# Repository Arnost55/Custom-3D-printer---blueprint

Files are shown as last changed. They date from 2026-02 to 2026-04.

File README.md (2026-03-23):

<div align="center">

  <h2>By Arnošt Dobrucký</h2>

  <p display="inline">
  
  <a href="https://creativecommons.org/licenses/by-nc/4.0/">
    </a> <a href="https://hackclub.com/">
    
  </a>

  </p>

  <h4>A homemade 3D printer that just works.     :)</h4>
</div>

<sub>This work is licensed under a
[Creative Commons Attribution-NonCommercial 4.0 International License](https://creativecommons.org/licenses/by-nc/4.0/).
</sub>

# Table of contents
- [About](#about)
- [BOM (Bill of Materials)](#bom-bill-of-materials)
- [How to Build the Blueprint 3D Printer](#how-to-build-the-blueprint-3d-printer)
  - [Section 1 — Materials and Tools](#section-1--materials-and-tools)
  - [Section 2 — Frame and Base Construction](#section-2--frame-and-base-construction)
  - [Section 3 — Machining the Parts](#section-3--machining-the-parts)
  - [Section 4 — Assembly](#section-4--assembly)
  - [Section 5 — Mounting the BTT Eddy Duo and Display](#section-5--mounting-the-btt-eddy-duo-and-display)
  - [Section 6 — Klipper Installation](#section-6--klipper-installation)
  - [Section 7 — Calibration](#section-7--calibration)
- [Images / Videos](#imagesvideos)
- [Future Plans](#future-plans)
- [Warranty](#warranty)
- [TO DO](#to-do)

---

# About

The Blueprint 3D printer is a fully custom-built FDM 3D printer designed and constructed from scratch by Arnošt and his grandfather. Every structural component was hand-machined from steel with no pre-made frame or kit involved. The project took a total of 420 hours across design, fabrication, assembly, and calibration.

---

### Specifications

| Spec | Value |
| --- | --- |
| Build Volume | 175mm × 210mm × 200mm |
| Frame Material | Standard steel |
| Motion System | **Cartesian** |
| Mainboard | BTT Manta E3EZ v1.0 |
| Hotend | BIQU H2 V2S Lite |
| Nozzle Diameter | 0.4mm |
| Heated Bed | Yes 235mm × 235mm |
| Extruder Type | Direct Drive |
| Bed Leveling Probe | BTT Eddy Duo |
| Stepper Motors | 3× BIQU NEMA 17 |
| Power Supply | 24V — 300W |
| Control Board Host | BTT CB1 |
| Display | BTT TFT35 |
| Firmware | Klipper |
| Web Interface | Mainsail |
| Print Surface | Tape (e.g. Duct tape) |
| Max Hotend Temp | 250°C |
| Max Bed Temp | 80°C  |

---

### Key Features

- Fully custom steel frame — no off-the-shelf structural parts
- Klipper firmware with Mainsail web interface for remote control and monitoring
- BTT Eddy probe for automatic bed mesh compensation
- Custom-machined motor mounts, bed holder, and extruder mount
- Internal cable management with pre-drilled routing holes
- PSU and mainboard housed inside the base for a clean build
- Painted black steel finish throughout

# BOM (bill of materials)

| Item Description | SKU | Qty | Unit Price (USD) | Total (USD) |
| --- | --- | --- | --- | --- |
| [GT2 Timing Pulley 16/20 Teeth (20 teeth-Width 6mm-bore 8mm/10pcs)](https://biqu.equipment/products/10pcs-gt2-timing-pulley-20-teeth-alumium-bore-5mm-fit-for-gt2-belt-width-6mm-with-lower-price-for-3d-printer-part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) | WCL000020*10 | 1 | $7.21 | 7.21 |
| [BIQU H2 V2S Lite Extruder Complete Kit](https://biqu.equipment/products/h2-v2s-lite?variant=40121207554146) | 1060000581 | 1 | $58.06 | 58.06 |
| [GT2-6mm Open Timing Belt (Rubber Black/6MM/10m)](https://biqu.equipment/products/hot-sale-10meter-gt2-6mm-open-timing-belt-width-6mm-gt2-belt-for-3d-printer-parts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) | 3020040150*10 | 1 | $9.48 | 9.48 |
| [BIQU Nema17 c42 motor CNC stepper motor (Length 33mm)](https://biqu.equipment/products/nema17-c42-motor-cnc-stepper-motor-length-33mm-stepping-motor-1-33a-for-3d-printer-for-cnc-xyz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) | 3010080001 | 3 | $11.80 | 35.39 |
| [BIGTREETECH Eddy Duo (Support USB or CAN)](https://biqu.equipment/products/bigtreetech-eddy?variant=41018205438050) | 1060000710 | 1 | $19.64 | 19.64 |
| [Flexible shaft Coupler 58mm (58/Black/4pcs)](https://biqu.equipment/products/3d-printer-stepper-motor-flexible-coupling-coupler-shaft-couplings-5mm-8mm-25mm-flexible-shaft-freeshipping-1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) | 3010050224*4 | 1 | $6.64 | 6.64 |
| [BIGTREETECH TFT35 SPI V2.1 Touch Screen for CB1](https://biqu.equipment/collections/lcd-screen/products/bigtreetech-tft35-spi-v2-1-touchscreen-io2can-module) | 1040000035 | 1 | $14.29 | 14.29 |
| [BIGTREETECH Manta E3EZ V1.0 + 5pcs EZ2209 + CB1 V2.2](https://biqu.equipment/products/bigtreetech-manta-e3ez-v1-0-for-ender3-ender3pro-ender5?variant=40214245081186) | 1020000405+… | 1 | $58.90 | 58.9 |
| [Wires](https://www.aliexpress.com/item/1005006801644262.html?spm=a2g0o.order_list.order_list_main.5.73a21802GiWhg9) | _____ | 4 | _____ | 13.58 |
| [T8 Lead Screw THSL-300-8D Trapezoidal Rod](https://www.aliexpress.com/item/1005003312523975.html?spm=a2g0o.order_list.order_list_main.36.73a21802GiWhg9) | _____ | 2 | $7.04 | 7.04 |
| [Meanwell PSU 350W](https://www.aliexpress.com/item/1005006092154615.html?spm=a2g0o.order_list.order_list_main.42.73a21802GiWhg9) | _____ | 1 | $40.34 | 40.34 |
| [Linear Rails](https://www.aliexpress.com/item/1005009577277063.html?spm=a2g0o.order_list.order_list_main.30.73a21802GiWhg9) | _____ | 3 | $18.81 | 56.43 |
| [Heat bed 235x235](https://www.aliexpress.com/item/1005007288279620.html?spm=a2g0o.order_list.order_list_main.11.73a21802GiWhg9) | _____ | 1 | $22.64 | 22.64 |
| Steel — from my grandpas garage | _____ | _____ | _____ | not yet defined |
| TOTAL: |  |  |  | 354.64 |

# How to Build the Blueprint 3D Printer

This guide explains how to build the custom steel-frame 3D printer from scratch. It covers everything from picking your materials to getting your first print. There is no pre-made kit for this — every part is made by hand. You will need basic metalworking skills, access to a drill and grinder, and patience.

## Section 1 — Materials and Tools

### Overview

Before you start cutting anything you need to have everything ready. This printer is built almost entirely from steel. You will also need a set of standard 3D printer electronics.

### What You Need

**Structural materials**

- Standard steel flat bar and sheet — for the base plate, Z-axis base, bed holder, motor mounts, and extruder mount
- Linear rails (1x for X-axis, 1x for Z-axis)
- Linear rods (1x for Z-axis)
- Lead screw with brass nut (for Z-axis)
- Aluminium extrusion or steel rod for frame uprights
- The display mount (needs to be 3D printed)
- The BTT eddy mount (needs to be 3D printed)

**Electronics**

- Mainboard (BTT Manta E3EZ v1.0)
- BTT CB1 v2.2 (runs Klipper on the printer)
- BTT  5pcs EZ2209 (the endstops)
- Stepper motors x3 (X, Y, Z)
- Heated bed 235×235
- BIQU H2 V2S Lite (the hotend)
- Power supply unit (PSU) — 24V 300W
- BTT Eddy probe (for bed leveling)
- BTT SPI 35 (The display)

**Consumables**

- Steel bolts, nuts, and washers in various sizes (M3, M4, M5)
- Stepper motor couplers
- GT2 belt and pulleys for X and Y axes
- Cable sleeves and cable ties
- Black spray paint

**Tools**

- Drill and drill bits (including metal drill bits)
- Angle grinder with cutting disc
- Files (flat and round)
- Steel square
- Vernier calipers
- Tap and die set (M3, M4, M5)
- Screwdrivers and hex keys
- Wire stripper and crimping tool
- Multimeter
- Computer with SSH access

## Section 2 — Frame and Base Construction

### Overview

The base is the foundation of the whole printer. If it is not flat and square everything built on top of it will have problems. Take your time here. We used standard steel throughout because it was the most rigid material after testing several options.

### Steps

1. **Cut the base plate** — Cut your main base plate from steel sheet to your chosen dimensions. The base needs to be large enough to house the PSU and mainboard inside it. Deburr all edges after cutting.
2. **Cut the Z-axis base** — Cut the smaller plate that the Z-axis frame will bolt onto. This sits on top of the main base plate.
3. **Mark and drill the mounting holes** — Place the Z-axis base on top of the main base plate and mark where the bolts need to go. Drill these holes carefully. Use a centre punch before drilling so the bit does not wander.
4. **Test fit everything** — Bolt the Z-axis base to the main base plate and check that it sits flat with no rocking. If it rocks, file down the high spots until it sits flat.
5. **Build the Z-axis frame uprights** — Cut and shape the vertical steel pieces that form the Z-axis frame. These need to be the same height and perfectly straight. Check with a square at every step. If anything is leaning or twisted, fix it before moving on.
6. **Bolt the Z-axis frame together** — Assemble the Z-axis frame and test fit it on the base. Check from multiple angles that it is straight and square. This step often requires making replacement parts — do not rush it.

## Section 3 — Machining the Parts

### Overview

Every bracket, mount, and holder in this printer is custom made from steel. None of these parts are bought. You make each one by cutting, drilling, and filing steel until it fits correctly. Measure everything twice before cutting.

### Steps

1. **Drill the linear rail mounting holes** — Mark and drill the holes for the linear rails on the Z-axis and X-axis frames. These holes must be accurate — rails that are even slightly crooked will cause binding during movement.
2. **Make the bed mounting bracket** — Cut and drill the bracket that holds the bed carriage to the Y-axis. Test fit it to the rods and adjust until it sits straight.
3. **Make the Y-axis rod mount** — Cut a custom steel piece that secures the Y-axis linear rods to the base. Measure the rod spacing carefully before cutting.
4. **Make the stepper motor mounts** — Cut one mount for each axis (X, Y, Z, and extruder). Each one is a different shape because each motor sits in a different position. Cut, file, and test fit each one before drilling the final bolt holes.
5. **Make the bed holder** — Cut the main bed holder from steel. This piece holds the heated bed flat so it needs to be as flat as possible. Check it against a flat surface and file down any high spots.
6. **Drill cable routing holes** — Plan the path for every cable in the printer before drilling. Mark each hole, drill it, and deburr it. Running cables through clean holes protects the insulation.
7. **Mount the PSU inside the base** — Cut any required opening for the PSU and bolt it inside the base. Make sure it is fixed firmly with no movement.
8. **Install the mainboard** — Bolt the mainboard into its housing using standoffs so it does not touch bare metal. Position it so all its connectors line up with the port holes you will cut next.
9. **Cut the port holes** — Mark the positions of the mainboard connectors on the outside of the base. Cut each hole carefully and file it smooth. Test fit a plug through each one before moving on.
10. **Make the extruder mount** — Cut the extruder mount from steel and shape it to hold the extruder at the correct position on the X-axis carriage. Drill and tap the bolt holes.
11. **Drill ventilation holes** — Drill ventilation holes in the areas of the base near the PSU and mainboard. These keep the electronics cool during long prints.

## Section 4 — Assembly

### Overview

Assembly is where everything comes together. Work through each axis one at a time. Test movement as you go — do not wait until everything is assembled before checking that axes move correctly.

### Steps

1. **Assemble the heated bed frame** — Bolt the bed frame together and run the heated bed wiring at the same time. Leave enough slack in the cable for the bed to move on the Y-axis.
2. **Assemble the X-axis** — Mount the linear rails, fit the carriage, and run the belt. Tension the belt until there is no slack but not so tight that it strains the motor. Test carriage travel across the full length.
3. **Assemble the Y-axis** — Fit the bed carriage onto the Y-axis rods and tension the belt. Check the full travel length. If the bed cannot reach the ends of its intended range, check the mounting geometry and adjust.
4. **Attach the extruder assembly** — Mount the extruder mount onto the X-axis carriage and bolt the extruder to it. Move the carriage to different positions and measure the nozzle height above the bed at each spot to confirm it is consistent.
5. **Mount the build plate** — Fit the heated bed onto its holder using four springs and thumb screws, one at each corner. Set each spring to roughly the same compression to give yourself a level starting point.
6. **Install the display and probe** — Mount the front display in its cutout and wire it to the mainboard. Mount the BTT Eddy probe next to the nozzle and wire it up.
7. **Connect all wiring** — Run every cable — motors, endstops, thermistors, heater cartridges — through the routing holes to the mainboard. Connect each one to the correct pin. Check every connection against your wiring diagram before powering on.
8. **Paint the frame** — Partially disassemble the frame and sand all steel surfaces. Apply thin coats of black spray paint and let each coat cure before adding the next. Reassemble after the final coat is fully dry.

## **Section 5 — Mounting the BTT Eddy Duo and Display**

**BTT Eddy Duo Mount**

1. Print the 3D model of the BTT eddy holder and mount it. The probe needs to sit at a fixed and measured distance from the nozzle — both horizontally and vertically — because this offset gets entered into the Klipper config and must be accurate.
2. Drill two mounting holes in the bracket to match the probe's bolt pattern.
3. Bolt the bracket to the X-axis carriage. Make sure it is rigid with no flex or wobble — if the probe moves during printing the bed mesh will be inaccurate.
4. Route its cable back along the X-axis carriage to the mainboard, securing it with cable ties so it does not hang loose near moving parts.
5. Measure the exact X and Y offset from the nozzle tip to the centre of the probe and write these values down. You will need them when setting up the probe in printer.cfg.

**Display Mount**

1. Choose a position on the front face of the base enclosure where the display will sit — it should be easy to see and reach while the printer is running.
2. Mark the outline of the display cutout on the steel and cut it out carefully with an angle grinder or drill and file. Cut slightly smaller than needed and file to the final size so the display fits snugly.
3. Drill the four corner bolt holes for the display mounting screws.
4. Bolt the display into the cutout from the inside. Use washers under the bolt heads so the display panel does not get cracked from overtightening.
5. Route the display cable through the nearest routing hole to the mainboard and connect it to the correct port.

## Section 6 — Klipper Installation

### Overview

Klipper is the firmware that runs the printer. It runs on the BTT CB1 and talks to the mainboard over USB. Mainsail is the web interface you use to control and monitor the printer from any browser on your network.

### Steps

1. **Flash the CB1** — Download the BTT CB1 OS image from [here](https://github.com/bigtreetech/CB1/releases) (specifically the version 2.3.4 , which works), extract it and flash it to a microSD card with Balena etcher . Insert it into the CB1, boot it up, and connect it to your network. Get the IP address and connect over SSH.
2. **Compile Klipper firmware** — On the CB1, go to the Klipper folder and run `make menuconfig`. Select the correct settings which are: STM32G0B1 with a "8KiB bootloader" "8 MHz crystal” and "USB (on PA11/PA12)”. Then run `make` to compile the firmware binary.
3. **Flash Klipper to the mainboard** — Put the mainboard into DFU mode (hold the BOOT button and push the RST at the same time). Now run `lsusb` you should see something like “STM32 in DFU mode” copy the id and run `make flash FLASH_DEVICE=<the id>`. It should flash it.
4. **Compile and Flash Klipper for the BTT eddy duo** — On the CB1, go to the Klipper folder and run `make menuconfig`. Select the correct settings for your mainboard's chip. Then run `make` to compile the firmware binary. Disconnect the BTT eddy cable. Push the boot button besides the connection pins [(More here)](https://github.com/krautech/btt-eddy-guide) and run `lsusb` and copy the id of something like “RPI Boot”  and flash it with `make flash FLASH_DEVICE=<the id>`.
5. **Download the configs** — This is the most important step. Download the Klipper configs from the Software folder and upload everything to the config tab in Mainsail and restart the firmware.
6. **Test each axis** — Use Mainsail to jog each axis and check it moves in the right direction. If a motor goes the wrong way add `dir_pin: !` in the config to invert it.
7. **Test homing** — Run a full home sequence and confirm all three axes home correctly without crashing.

## Section 7 — Calibration

### Overview

Calibration is not a one-time thing. You work through each step, print a test, measure it, adjust, and repeat. On a scratch-built printer this takes many sessions. Be patient and change only one thing at a time so you can see what each change does.

### Steps

1. **PID tune the hotend** — In Klipper run `PID_CALIBRATE HEATER=extruder TARGET=215`. Save the result with `SAVE_CONFIG`. This makes the hotend temperature stable.
2. **PID tune the heated bed** — Run `PID_CALIBRATE HEATER=heater_bed TARGET=55`. Save the result. This makes the bed temperature stable.
3. **Calibrate extruder rotation distance** — Mark 100mm of filament from the extruder entry. Command Klipper to extrude 100mm. Measure how much filament actually moved. Calculate the corrected rotation distance with this formula: `new_rotation_distance = old_rotation_distance * (actual_mm / requested_mm)`. Update the config and repeat until it is accurate.
4. **Set the z-offset** — Home the printer and use the paper test or probe method to find the exact distance between the nozzle and the bed. Save this as your z-offset. This controls how close the first layer is to the bed.
5. **Run bed mesh calibration** — Use the BTT Eddy probe to scan the bed surface and generate a mesh. Save it to the config. Klipper will use this mesh to compensate for any unevenness in the bed during printing.
6. **Print a test piece** — Print a small flat square to check the first layer and a 20mm cube to check dimensions. Measure the cube with calipers. Adjust rotation distances if the dimensions are off.
7. **Fix any issues** — Common problems and fixes:
    - *First layer not sticking* — lower the z-offset slightly
    - *Over-extrusion* — reduce the rotation distance
    - *Layer shifting* — check belt tension, increase motor current, or reduce print speed and acceleration
    - *Inconsistent extrusion* — check extruder grip tension and re-calibrate rotation distance
    - *Binding on an axis* — check rod and rail alignment, re-check belt tension
8. **Run a final mesh and save all settings** — After all issues are resolved, run a fresh bed mesh, re-confirm the z-offset, and save everything to the config. Add comments in the config file explaining what each setting does.

# Images/Videos

> CAD
> 
> 
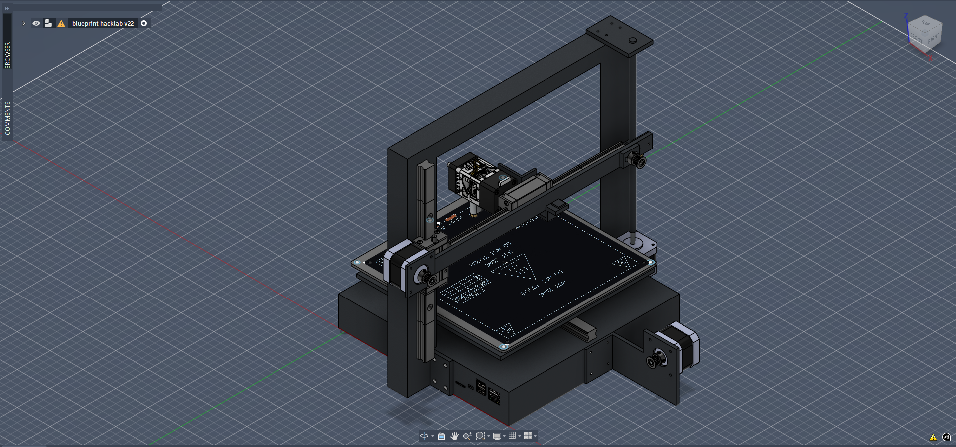
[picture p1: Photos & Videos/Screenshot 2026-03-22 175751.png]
Screenshot 2026-03-22 175751.png
> 
> 
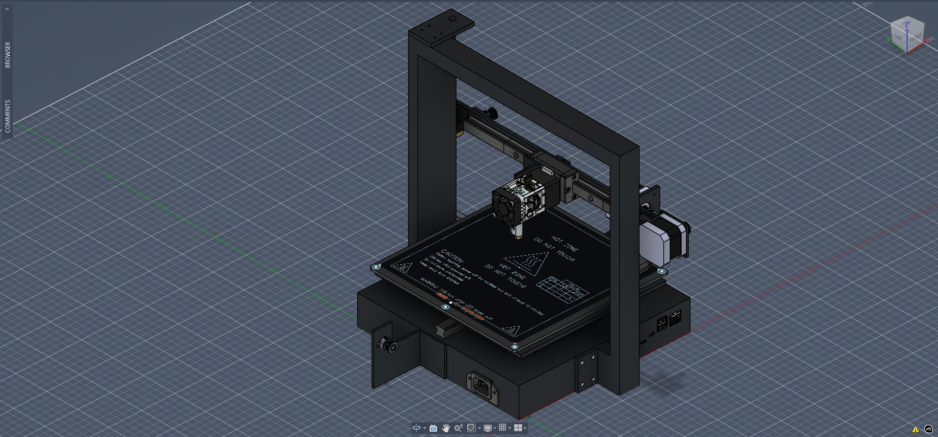
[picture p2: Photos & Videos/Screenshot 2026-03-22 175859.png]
Screenshot 2026-03-22 175859.png
> 
> 
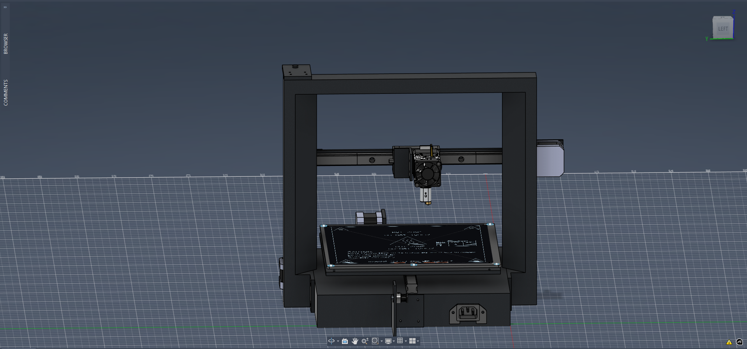
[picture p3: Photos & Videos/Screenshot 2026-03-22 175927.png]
Screenshot 2026-03-22 175927.png
> 
> 
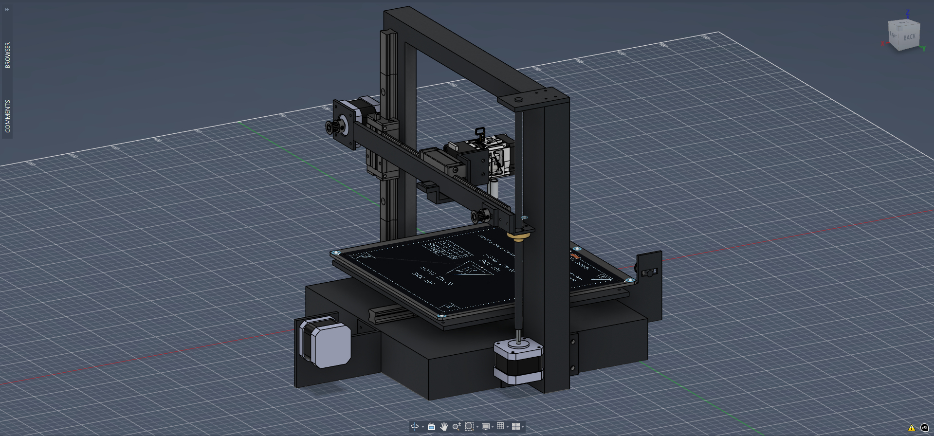
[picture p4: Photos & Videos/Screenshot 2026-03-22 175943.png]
Screenshot 2026-03-22 175943.png
> 
> 

> Printer IRL
> 
> 
> 
> 
> 
> 
> 
> 
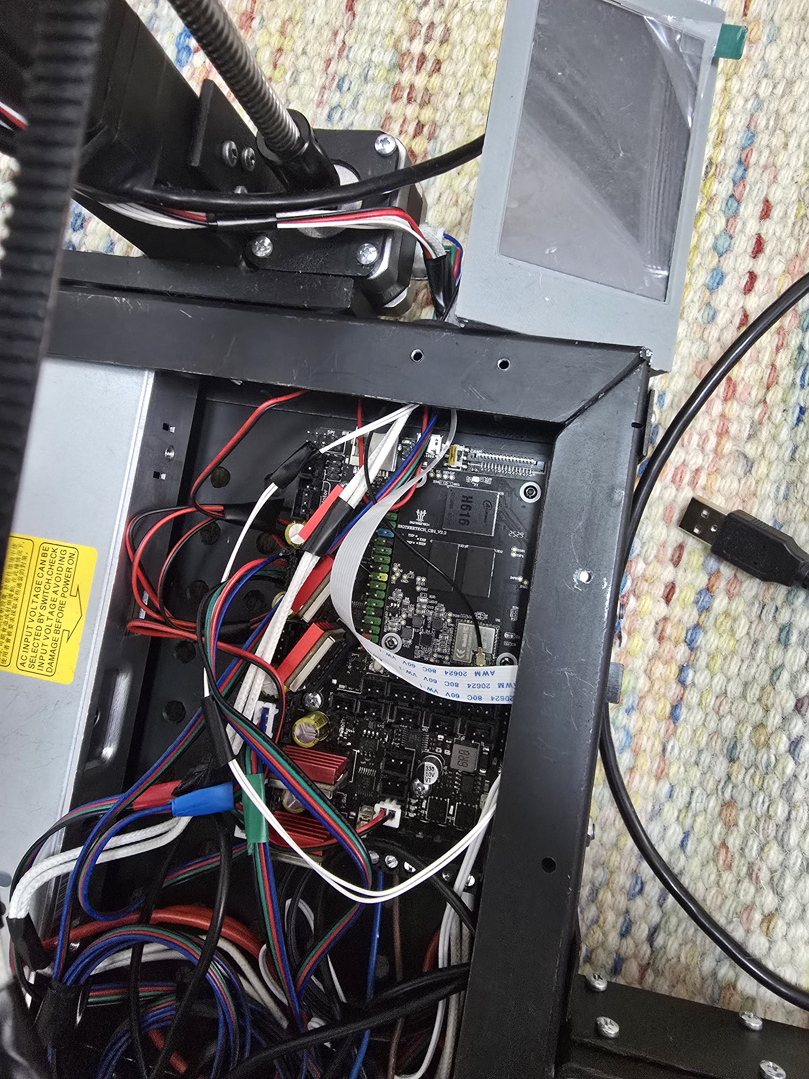
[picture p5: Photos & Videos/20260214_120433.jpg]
> 
> 

> video of the printer [here](https://photos.app.goo.gl/1GatzKqddWVSHqSS6)

## Wiring diagram

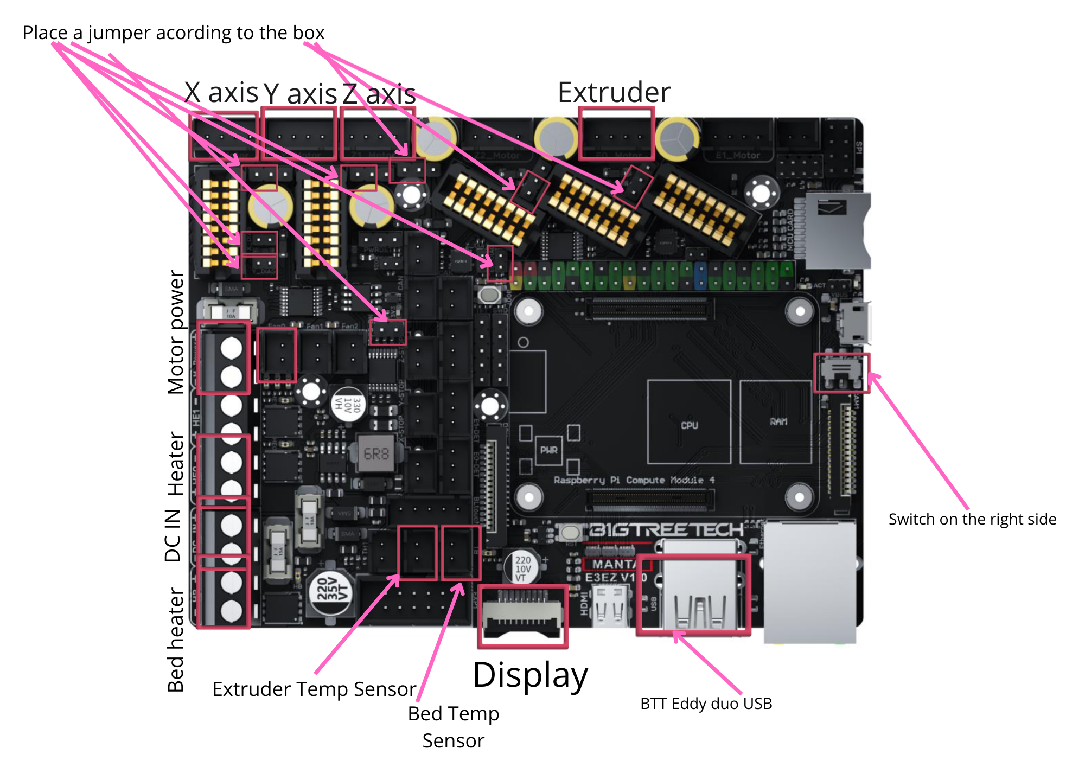
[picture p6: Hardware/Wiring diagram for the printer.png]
Wiring diagram for the printer.png


Wiring diagram for the printer.png

# Future plans

This project has no future plans.

The Blueprint 3D printer was built as a one-time project specifically for the Blueprint programme. It was never intended to be a product, a kit, or a continued development effort. The goal was to design and build a fully functional 3D printer from scratch, and that goal has been completed.

No further versions are planned. No improvements, upgrades, or continuations of this project are in development. This document and the build journals represent the full and final record of the project from start to finish.

# Warranty

## ⚠️ Disclaimer

This guide is provided for informational purposes only. By following this guide you accept full responsibility for your own safety and for any outcome that results from building or using this printer.

We are not responsible for any of the following:

- Personal injury or death caused by the use of tools, machinery, electricity, or the finished printer
- Damage to property, equipment, or materials during or after the build process
- Fire, electrical faults, or overheating caused by incorrect wiring, misconfigured firmware, or faulty components
- Data loss or software damage caused by following the Klipper installation or configuration steps
- Any costs, losses, or damages that arise from errors or omissions in this guide

This printer involves working with mains-voltage power supplies, high-temperature components, and moving mechanical parts. If you are not confident working with any of these, seek help from someone who is qualified before proceeding.

This guide describes how **we** built **our specific printer**. Your build will be different. Dimensions, materials, wiring, and configuration will vary depending on the parts you use. Always verify information against the official documentation for your specific components.

**Build at your own risk.**

# TO DO

- [x]  Order Parts
- [x]  Make a high resolution 3D model, CAD
- [x]  Assemble
- [x]  Make endstops
- [x]  Install klipper
- [x]  Calibrate
- [ ]  Ship it to blueprint
- [x]  GOOD VIBES, FUN
- [x]  Publish config files

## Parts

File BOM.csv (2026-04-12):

Item Description | SKU | Qty | Unit Price (USD) | Total (USD)
GT2 Timing Pulley 16/20 Teeth (20 teeth-Width 6mm-bore 8mm/10pcs) | WCL000020*10 | 1 | $7.21 | 7.21
BIQU H2 V2S Lite Extruder Complete Kit | 1060000581 | 1 | $58.06 | 58.06
GT2-6mm Open Timing Belt (Rubber Black/6MM/10m) | 3020040150*10 | 1 | $9.48 | 9.48
BIQU Nema17 c42 motor CNC stepper motor (Length 33mm) | 3010080001 | 3 | $11.80 | 35.39
BIGTREETECH Eddy Duo (Support USB or CAN) | 1060000710 | 1 | $19.64 | 19.64
Flexible shaft Coupler 58mm (58/Black/4pcs) | 3010050224*4 | 1 | $6.64 | 6.64
BIGTREETECH TFT35 SPI V2.1 Touch Screen for CB1 | 1040000035 | 1 | $14.29 | 14.29
BIGTREETECH Manta E3EZ V1.0 + 5pcs EZ2209 + CB1 V2.2 | 1020000405+... | 1 | $58.90 | 58.9
Wires | _____ | 4 | _____ | 13.58
T8 Lead Screw THSL-300-8D Trapezoidal Rod | _____ | 2 | $7.04 | 7.04
Meanwell PSU 350W | _____ | 1 | $40.34 | 40.34
Linear Rails | _____ | 3 | $18.81 | 56.43
Heat bed 235x235 | _____ | 1 | $22.64 | 22.64
Steel --- from my grandpas garage | _____ | _____ | _____ | 8.36
TOTAL: |  |  |  | 358.00

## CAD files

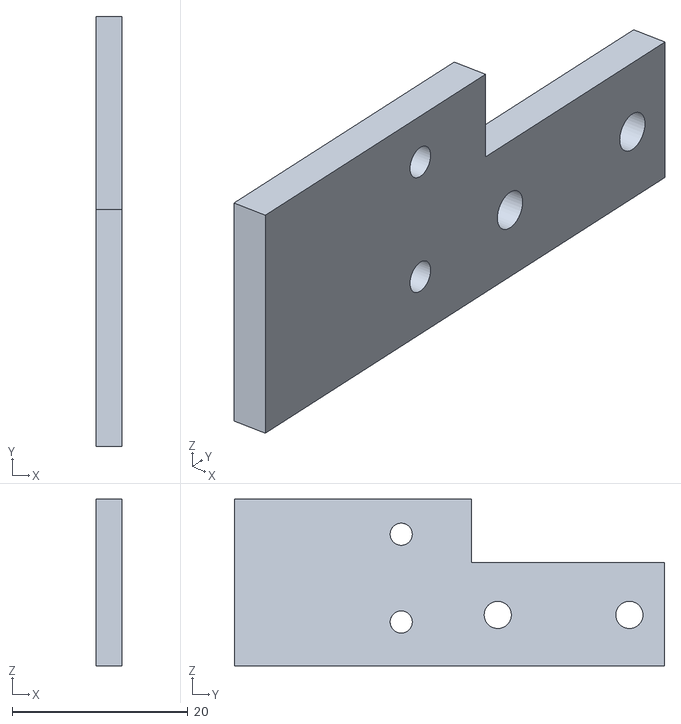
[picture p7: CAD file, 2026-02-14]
Hardware/Parts for 3D printing/BTT eddy holder for extruder (my creation).stl
3.00 x 49.0 x 19.0

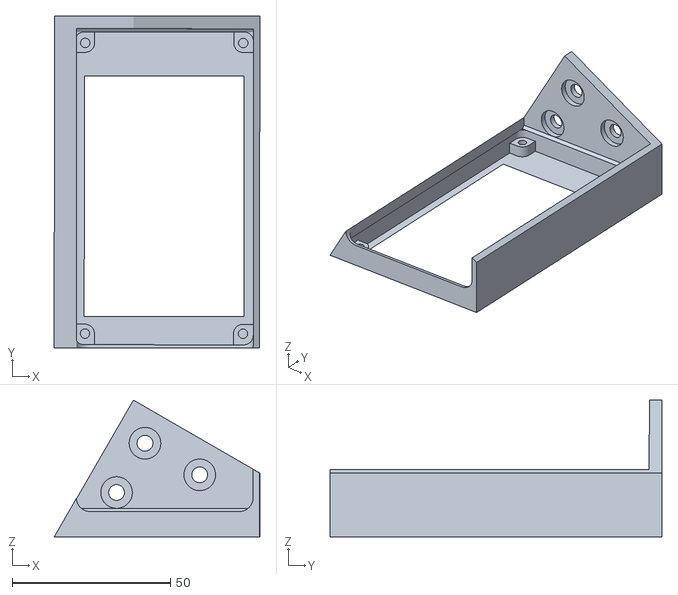
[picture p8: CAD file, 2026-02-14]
Hardware/Parts for 3D printing/BTT TFT35 SPI holder (not my creation).stl
65.1 x 105.1 x 43.3

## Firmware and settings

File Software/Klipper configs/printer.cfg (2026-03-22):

[include mainsail.cfg]
[include btt_eddy.cfg]
[include KAMP/KAMP_Settings.cfg]  
[include macros.cfg]
# host MCU service is preinstalled and ready to use with:
[exclude_object]
[mcu CB1]
serial: /tmp/klipper_host_mcu

# This file contains common pin mappings for the BIGTREETECH Manta E3EZ
# To use this config, the firmware should be compiled for the
# STM32G0B1 with a "8KiB bootloader" "8 MHz crystal"
# and "USB (on PA11/PA12)" or "CAN bus (on PB12/PB13)".


[bed_screws]
screw1: 20, 40
screw2: 173, 50
screw3: 20, 190
screw4: 173, 190
screw5: 100, 125

[stepper_x]
step_pin: PA14
dir_pin: PA10
enable_pin: !PA13
microsteps: 16
rotation_distance: 40
endstop_pin: tmc2209_stepper_x:virtual_endstop
position_endstop: 0
position_min: 0
position_max: 175
homing_speed: 50

[stepper_y]
step_pin: PC8
dir_pin: !PA15
enable_pin: !PC14
microsteps: 16
rotation_distance: 40
endstop_pin: tmc2209_stepper_y:virtual_endstop
position_endstop: -8
position_max: 220
position_min: -9
homing_speed: 50

[stepper_z]
step_pin: PD2
dir_pin: !PD4
enable_pin: !PD3
microsteps: 16
rotation_distance: 8
endstop_pin: probe:z_virtual_endstop
#position_endstop: 0
position_max: 150
position_min: -5
homing_positive_dir: False

[extruder]
max_extrude_cross_section: 5
step_pin: PD5
dir_pin: PD6
enable_pin: !PB3
microsteps: 16
rotation_distance: 3.465
nozzle_diameter: 0.400
filament_diameter: 1.750
heater_pin: PB11 #HE0
sensor_type: EPCOS 100K B57560G104F
sensor_pin: PA4 #TH0
control: pid
pid_Kp: 21.527
pid_Ki: 1.063
pid_Kd: 108.982
min_temp: 0
max_temp: 250
max_extrude_only_distance: 101


[heater_bed]
heater_pin: PB2 #HB
sensor_type: EPCOS 100K B57560G104F #Generic 3950
sensor_pin: PA3 #TB
control: watermark
min_temp: 0
max_temp: 130

[heater_fan fan1]
pin: PA8

[mcu]
serial: /dev/serial/by-id/usb-Klipper_stm32g0b1xx_1D00330008504E5238363120-if00

[printer]
kinematics: cartesian
max_velocity: 300
max_accel: 2875
max_z_velocity: 5
max_z_accel: 100

########################################
# TMC2209 configuration
########################################

[tmc2209 stepper_x]
uart_pin: PB8
diag_pin: PC4
run_current: 0.800
stealthchop_threshold: 999999
driver_SGTHRS: 50

[tmc2209 stepper_y]
uart_pin: PC9
diag_pin: PB0
run_current: 0.800
stealthchop_threshold: 999999
driver_SGTHRS: 67

#[tmc2209 stepper_z]
#uart_pin: PD0
#diag_pin: PC6
#run_current: 0.650
#stealthchop_threshold: 999999

[tmc2209 extruder]
uart_pin: PD1
run_current: 0.800
stealthchop_threshold: 999999
driver_SGTHRS: 75

#[tmc2209 extruder1]
#uart_pin: PB5
#run_current: 0.800
#stealthchop_threshold: 999999


[board_pins]
aliases:
    # EXP1 header
    EXP1_1=PC1, EXP1_3=PC3, EXP1_5=PC0, EXP1_7=PA2, EXP1_9=<GND>,
    EXP1_2=PC2,  EXP1_4=<RST>, EXP1_6=PA0, EXP1_8=PA1, EXP1_10=<5V>

#*# <---------------------- SAVE_CONFIG ---------------------->
#*# DO NOT EDIT THIS BLOCK OR BELOW. The contents are auto-generated.
#*#
#*# [probe_eddy_current btt_eddy]
#*# reg_drive_current = 15
#*# calibrate =
#*# 	0.050000:3160955.966,0.090000:3160830.088,0.130000:3160667.395,
#*# 	0.170000:3160267.567,0.210000:3159838.550,0.250000:3159450.710,
#*# 	0.290000:3159061.682,0.330000:3158699.956,0.370000:3158329.886,
#*# 	0.410000:3157987.115,0.450000:3157664.917,0.490000:3157349.299,
#*# 	0.530000:3157045.791,0.570000:3156747.816,0.610000:3156447.984,
#*# 	0.650000:3156161.835,0.690000:3155899.647,0.730000:3155632.457,
#*# 	0.770000:3155359.486,0.810000:3155122.028,0.850000:3154884.857,
#*# 	0.890000:3154661.593,0.930000:3154424.740,0.970000:3154199.084,
#*# 	1.010000:3153965.879,1.050000:3153765.518,1.090000:3153557.020,
#*# 	1.130000:3153363.322,1.170000:3153163.036,1.210000:3152975.610,
#*# 	1.250000:3152787.673,1.290000:3152615.687,1.330000:3152445.939,
#*# 	1.370000:3152274.581,1.410000:3152100.277,1.450000:3151939.223,
#*# 	1.490000:3151781.806,1.530000:3151643.057,1.570000:3151499.594,
#*# 	1.610000:3151347.413,1.650000:3151211.322,1.690000:3151070.988,
#*# 	1.730000:3150939.431,1.770000:3150811.186,1.810000:3150688.234,
#*# 	1.850000:3150551.469,1.890000:3150448.784,1.930000:3150332.640,
#*# 	1.970000:3150214.462,2.010000:3150104.381,2.050000:3150000.451,
#*# 	2.090000:3149902.176,2.130000:3149796.817,2.170000:3149697.250,
#*# 	2.210000:3149602.114,2.250000:3149504.245,2.290000:3149417.166,
#*# 	2.330000:3149331.354,2.370000:3149241.547,2.410000:3149147.093,
#*# 	2.450000:3149058.988,2.490000:3148989.590,2.530000:3148904.339,
#*# 	2.570000:3148824.327,2.610000:3148746.575,2.650000:3148673.608,
#*# 	2.690000:3148592.956,2.730000:3148526.523,2.770000:3148449.111,
#*# 	2.810000:3148376.023,2.850000:3148319.428,2.890000:3148246.758,
#*# 	2.930000:3148180.486,2.970000:3148113.320,3.010000:3148052.284,
#*# 	3.050000:3147994.230,3.090000:3147945.016,3.130000:3147889.788,
#*# 	3.170000:3147823.223,3.210000:3147769.747,3.250000:3147718.077,
#*# 	3.290000:3147655.270,3.330000:3147602.323,3.370000:3147553.149,
#*# 	3.410000:3147502.781,3.450000:3147459.637,3.490000:3147416.990,
#*# 	3.530000:3147370.119
#*#
#*# [temperature_probe btt_eddy]
#*# calibration_temp = 37.487169
#*#
#*# [bed_mesh default]
#*# version = 1
#*# points =
#*# 	0.613394, 0.533224, 0.457576, 0.378611, 0.298735, 0.225417, 0.142637, 0.056205, -0.027767
#*# 	0.632278, 0.566694, 0.494116, 0.422632, 0.352063, 0.278768, 0.202417, 0.133512, 0.046816
#*# 	0.570780, 0.490288, 0.421804, 0.352063, 0.282805, 0.213092, 0.138683, 0.064534, -0.006340
#*# 	0.479372, 0.413179, 0.347324, 0.278768, 0.205085, 0.143855, 0.065193, -0.005203, -0.083248
#*# 	0.393251, 0.321037, 0.255946, 0.183800, 0.112363, 0.045099, -0.028972, -0.104348, -0.167042
#*# 	0.299319, 0.231330, 0.169385, 0.095130, 0.026481, -0.044757, -0.113691, -0.188923, -0.262954
#*# 	0.197079, 0.130316, 0.063074, -0.005203, -0.075306, -0.138631, -0.218425, -0.289331, -0.358669
#*# 	0.095130, 0.036769, -0.027767, -0.093817, -0.161699, -0.231352, -0.299365, -0.369629, -0.432366
#*# 	0.033993, -0.034082, -0.091882, -0.161699, -0.219704, -0.294083, -0.365976, -0.427231, -0.504162
#*# x_count = 9
#*# y_count = 9
#*# mesh_x_pps = 2
#*# mesh_y_pps = 2
#*# algo = bicubic
#*# tension = 0.2
#*# min_x = 49.999999999999986
#*# max_x = 164.95999999999998
#*# min_y = 20.0
#*# max_y = 214.96000000000004

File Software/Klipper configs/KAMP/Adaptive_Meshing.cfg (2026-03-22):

# # # Klipper Adaptive Meshing # # #

# Heads up! If you have any other BED_MESH_CALIBRATE macros defined elsewhere in your config, you will need to comment out / remove them for this to work. (Klicky/Euclid Probe)
# You will also need to be sure that [exclude_object] is defined in printer.cfg, and your slicer is labeling objects.
# This macro will parse information from objects in your gcode to define a min and max mesh area to probe, creating an adaptive mesh!
# This macro will not increase probe_count values in your [bed_mesh] config. If you want richer meshes, be sure to increase probe_count. We recommend at least 5,5.

[gcode_macro BED_MESH_CALIBRATE]
rename_existing: _BED_MESH_CALIBRATE
gcode:

    {% set all_points = printer.exclude_object.objects | map(attribute='polygon') | sum(start=[]) %}                                # Gather all object points
    {% set bed_mesh_min = printer.configfile.settings.bed_mesh.mesh_min %}                                                          # Get bed mesh min from printer.cfg
    {% set bed_mesh_max = printer.configfile.settings.bed_mesh.mesh_max %}                                                          # Get bed mesh max from printer.cfg
    {% set probe_count = printer.configfile.settings.bed_mesh.probe_count %}                                                        # Get probe count from printer.cfg
    {% set kamp_settings = printer["gcode_macro _KAMP_Settings"] %}                                                                 # Pull variables from _KAMP_Settings
    {% set verbose_enable = kamp_settings.verbose_enable | abs %}                                                                   # Pull verbose setting from _KAMP_Settings
    {% set probe_dock_enable = kamp_settings.probe_dock_enable | abs %}                                                             # Pull probe dockable probe settings from _KAMP_Settings
    {% set attach_macro = kamp_settings.attach_macro | string %}                                                                    # Pull attach probe command from _KAMP_Settings
    {% set detach_macro = kamp_settings.detach_macro | string %}                                                                    # Pull detach probe command from _KAMP_Settings
    {% set mesh_margin = kamp_settings.mesh_margin | float %}                                                                       # Pull mesh margin setting from _KAMP_Settings
    {% set fuzz_amount = kamp_settings.fuzz_amount | float %}                                                                       # Pull fuzz amount setting from _KAMP_Settings
    {% set probe_count = probe_count if probe_count|length > 1 else probe_count * 2  %}                                             # If probe count is only a single number, convert it to 2. E.g. probe_count:7 = 7,7
    {% set max_probe_point_distance_x = ( bed_mesh_max[0] - bed_mesh_min[0] ) / (probe_count[0] - 1)  %}                            # Determine max probe point distance
    {% set max_probe_point_distance_y = ( bed_mesh_max[1] - bed_mesh_min[1] ) / (probe_count[1] - 1)  %}                            # Determine max probe point distance
    {% set x_min = all_points | map(attribute=0) | min | default(bed_mesh_min[0]) %}                                                # Set x_min from smallest object x point
    {% set y_min = all_points | map(attribute=1) | min | default(bed_mesh_min[1]) %}                                                # Set y_min from smallest object y point
    {% set x_max = all_points | map(attribute=0) | max | default(bed_mesh_max[0]) %}                                                # Set x_max from largest object x point
    {% set y_max = all_points | map(attribute=1) | max | default(bed_mesh_max[1]) %}                                                # Set y_max from largest object y point

    {% set fuzz_range = range((0) | int, (fuzz_amount * 100) | int + 1) %}                                                          # Set fuzz_range between 0 and fuzz_amount
    {% set adapted_x_min = x_min - mesh_margin - (fuzz_range | random / 100.0) %}                                                   # Adapt x_min to margin and fuzz constraints
    {% set adapted_y_min = y_min - mesh_margin - (fuzz_range | random / 100.0) %}                                                   # Adapt y_min to margin and fuzz constraints
    {% set adapted_x_max = x_max + mesh_margin + (fuzz_range | random / 100.0) %}                                                   # Adapt x_max to margin and fuzz constraints
    {% set adapted_y_max = y_max + mesh_margin + (fuzz_range | random / 100.0) %}                                                   # Adapt y_max to margin and fuzz constraints

    {% set adapted_x_min = [adapted_x_min , bed_mesh_min[0]] | max %}                                                               # Compare adjustments to defaults and choose max
    {% set adapted_y_min = [adapted_y_min , bed_mesh_min[1]] | max %}                                                               # Compare adjustments to defaults and choose max
    {% set adapted_x_max = [adapted_x_max , bed_mesh_max[0]] | min %}                                                               # Compare adjustments to defaults and choose min
    {% set adapted_y_max = [adapted_y_max , bed_mesh_max[1]] | min %}                                                               # Compare adjustments to defaults and choose min

    {% set points_x = (((adapted_x_max - adapted_x_min) / max_probe_point_distance_x) | round(method='ceil') | int) + 1 %}          # Define probe_count's x point count and round up
    {% set points_y = (((adapted_y_max - adapted_y_min) / max_probe_point_distance_y) | round(method='ceil') | int) + 1 %}          # Define probe_count's y point count and round up

    {% if (([points_x, points_y]|max) > 6) %}                                                                                       # 
        {% set algorithm = "bicubic" %}                                                                                             # 
        {% set min_points = 4 %}                                                                                                    # 
    {% else %}                                                                                                                      # Calculate if algorithm should be bicubic or lagrange
        {% set algorithm = "lagrange" %}                                                                                            # 
        {% set min_points = 3 %}                                                                                                    # 
    {% endif %}                                                                                                                     # 

    {% set points_x = [points_x , min_points]|max %}                                                                                # Set probe_count's x points to fit the calculated algorithm
    {% set points_y = [points_y , min_points]|max %}                                                                                # Set probe_count's y points to fit the calculated algorithm
    {% set points_x = [points_x , probe_count[0]]|min %}
    {% set points_y = [points_y , probe_count[1]]|min %}

    {% if verbose_enable == True %}                                                                                                 # If verbose is enabled, print information about KAMP's calculations
        {% if printer.exclude_object.objects != [] %}

            { action_respond_info( "Algorithm: {}.".format(                                                                              
                (algorithm),                                                                                                            
            )) }

            { action_respond_info("Default probe count: {},{}.".format(                                                                  
                (probe_count[0]),                                                                                                       
                (probe_count[1]),                                                                                                       
            )) }

            { action_respond_info("Adapted probe count: {},{}.".format(                                                                  
                (points_x),                                                                                                             
                (points_y),                                                                                                             
            )) }
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

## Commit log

2025-12-03 made a low poly 3d model
    [blueprint hacklab.obj]
2025-12-08 deleted a file
    [blueprint hacklab.obj]
2025-12-10 3d model of the printer
2025-12-30 Add BOM section to README with item details
    Added a Bill of Materials (BOM) section with item details and pricing.
2025-12-30 Revise BOM section with links and formatting
    Updated the BOM section with links and improved formatting.
2025-12-30 Revise BOM with updated item details and links
    Updated the bill of materials section with new items and prices.
2025-12-31 full commit
    [BOM (2).csv, BOM.csv]
2026-01-23 new cad
2026-02-14 I am done :)
    [BTT TFT35 SPI holder (not my creation).stl, BTT eddy holder for extruder (my creation).stl]
2026-03-22 More details
    [Adaptive_Meshing.cfg, KAMP_Settings.cfg, Line_Purge.cfg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]
2026-03-23 Replace embedded video with a link
    Removed embedded video of the printer running at max acceleration and added a link to the video instead.
2026-04-12 Modify steel entry and update total cost in BOM
    Updated the quantity and price for steel in BOM.
    [BOM.csv]
